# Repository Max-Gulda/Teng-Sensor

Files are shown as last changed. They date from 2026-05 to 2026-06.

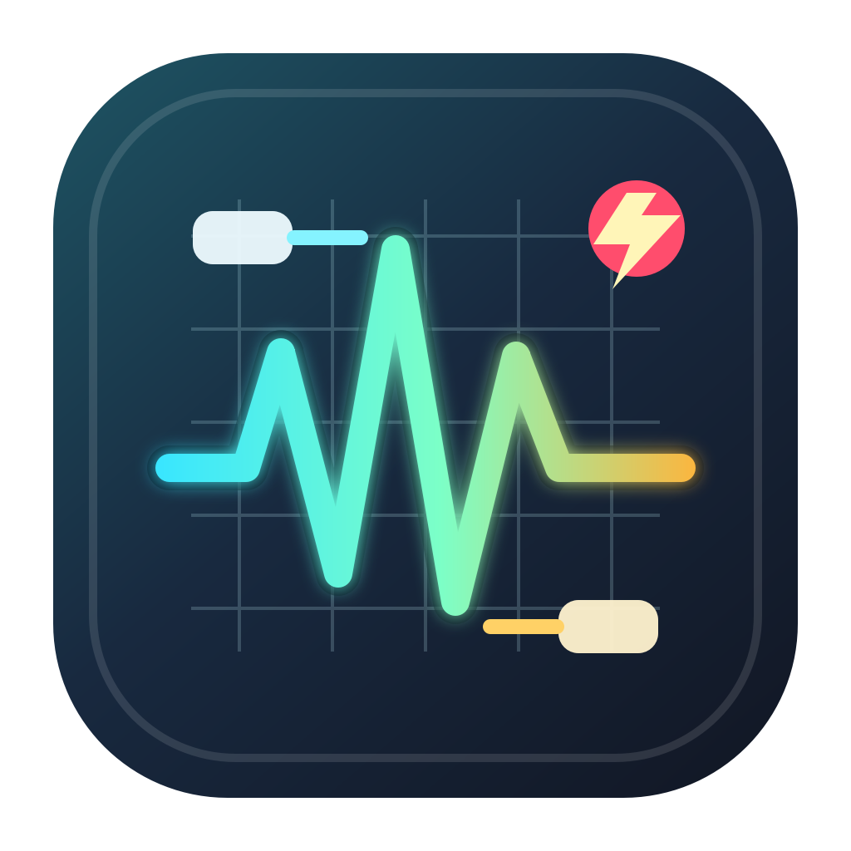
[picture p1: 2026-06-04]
gui/src/ecg_belt_gui/assets/teng-sensor-scope.png

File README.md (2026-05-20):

# TENG Sensor Scope

This repository contains two parts:

- `nrf54/`: Zephyr firmware for the Nordic **nRF54L15 DK target** (`nrf54l15dk/nrf54l15/cpuapp`) used by the course board setup
- `gui/`: a Python BLE scope GUI that displays calibrated ADS131M04 voltage streams

Minimal Zephyr RTOS firmware intended for the course proprietary board setup. The Zephyr build target used for this course setup is:

- `nrf54l15dk/nrf54l15/cpuapp`

The firmware samples **ADS131M04** 24-bit ADC data. All 4 ADC channels are enabled and streamed over BLE as signed raw counts. CH0 and CH1 are intended to be displayed as source voltage through the 100k/15k input dividers; CH2 and CH3 are direct ADC input voltage.

It transmits data over **Bluetooth LE** using custom GATT characteristics plus Nordic UART Service (NUS) for logs and scope commands.

## Attribution

Created by:

- **Jesper Sjöberg** — GitHub: [@repsejs](https://github.com/repsejs) — KTH: **@jessjobe**
- **Max Gulda** — GitHub: [@Max-Gulda](https://github.com/Max-Gulda) — KTH: **@gulda**

## Architecture

### Threads and priorities

| Thread | Priority | What it does | Key code |
|---|---:|---|---|
| Sampling | 5 | Reads ADC on ADS131M04 DRDY falling edges and queues data to BLE | `nrf54/src/sampling/sampling.c` |
| Bluetooth | 7 | Batches and transmits ADC notifications; manages connect/disconnect | `nrf54/src/bluetooth/bluetooth.c`, `nrf54/src/bluetooth/bt_*.c` |
| Main | default | Initialization + periodic CPU load logging | `nrf54/src/main.c` |

### Data flow

```text
ADS131M04 CH0-CH3 ─► sampling_thread ───────────────────────────────────────────────► BLE ADC channel (batched notifications)
LOG_* / printk ─────────────────────────────► NUS (BLE log backend)
```

### Source layout (firmware)

- `nrf54/src/ads131m04_spi/` — ADS131M04 SPI driver + configuration
- `nrf54/src/sampling/` — DRDY-driven sampling thread, queues ADC frames to BLE
- `nrf54/src/bluetooth/` — BLE GATT services, batching, queues, and notifications
- `nrf54/src/ble_log_backend/` — routes Zephyr `LOG_*` output over BLE (NUS)

### ADS131M04 notes

- The old `ads131m02_spi` module was renamed to `ads131m04_spi`.
- The driver parses 4 ADC channels and exposes CH0, CH1, CH2, and CH3 in `ads131m04_data_t`.
- The default setup in `ads131m04_full_setup()` enables all four channels.
- CH0 and CH1 have 100k/15k dividers and are converted to source voltage in the GUI.
- CH2 and CH3 have no divider and are converted to direct ADC input voltage in the GUI.
- The main custom BLE ADC payload carries timestamp + CH0 + CH1 + CH2 + CH3.
- Sampling is driven by the ADS131M04 DRDY pin. The default ADC OSR is 8192 (500 SPS), and the GUI can switch among the standard ADS131M04 output data rates.

## Build and run (VS Code + nRF Connect extension)

### Important (VS Code workspace)

When using the **nRF Connect for VS Code** extension, make sure the **opened workspace folder is `nrf54/`** (not the repo root). Otherwise the extension may not detect the application correctly.

### Prerequisites

- VS Code
- **nRF Connect for VS Code** extension installed (Nordic Semiconductor)
- A working nRF Connect SDK toolchain (the extension can install/manage this)
- The **course proprietary board** connected over USB (uses the nRF54L15 DK target)

### Open the project

1. Open this folder in VS Code.
2. In the nRF Connect sidebar:
   - Select the **application**: `nrf54/`
   - Select the board: `nrf54l15dk/nrf54l15/cpuapp`.

### Build

Use the nRF Connect extension’s **Build** action. This project uses Zephyr sysbuild (MCUboot enabled), matching:

```bash
cd nrf54
west build -b nrf54l15dk/nrf54l15/cpuapp --sysbuild
```

### Flash

Use the nRF Connect extension’s **Flash** action, or from a terminal:

```bash
west flash
```

### View logs / verify it runs

You have two common options:

- **UART/serial logs**: use the extension’s serial monitor, or:

```bash
west espresso
```

- **BLE logs over NUS**: connect with a NUS-capable client and view logs streamed by the BLE log backend (enabled in `nrf54/src/main.c`).

## IntelliSense note (students)

This repo is configured to work with VS Code’s **C/C++ IntelliSense**. For full, correct include paths/macros, build once so Zephyr generates:

- `nrf54/build/compile_commands.json`

After the first build, IntelliSense should work.

## Bluetooth DFU (nRF Device Manager)

After building, the build directory will contain a DFU package:

- `nrf54/build/dfu_application.zip`

To flash **over Bluetooth** using the **nRF Device Manager** mobile app:

1. Flash once over USB initially (so the device has the bootloader + BLE DFU enabled).
2. Power the device and connect to it in **nRF Device Manager**.
3. Choose **DFU / Update firmware** (wording varies by app version).
4. Select `dfu_application.zip` and start the update.
5. Wait for the device to reboot and reconnect.

## GUI (Python)

To run the BLE scope GUI:

```bash
cd gui
uv sync
uv run teng-sensor-scope
```

Use **Settings** in the GUI to choose visible channels and plot window length.

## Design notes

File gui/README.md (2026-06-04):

# TENG Sensor Scope GUI (Python)

Desktop GUI that connects over BLE and displays:

- Calibrated ADS131M04 channel voltages CH0, CH1, CH2, and CH3
- Per-channel visibility, plot window length, and display filter controls
- Dark and light UI themes
- CSV recordings saved under `Recordings/` in the repository root
- Firmware logs over NUS in the launching terminal

## Run (uv)

From the repo root:

```bash
cd gui
uv sync
uv run teng-sensor-scope
```

The old `uv run ecg-belt-gui` command remains as a compatibility alias.

## Voltage Scaling

- The firmware streams raw signed ADS131M04 counts.
- CH0 and CH1 use the 100k/15k voltage dividers and are displayed as source voltage.
- CH2 and CH3 have no divider and are displayed as direct ADC input voltage.
- Per-channel trim constants live in `src/ecg_belt_gui/app.py` as `CHANNEL_TRIM_GAIN` and `CHANNEL_TRIM_OFFSET_V`.

## Scope Settings

Use the **Settings** button to:

- Hide or show individual channels.
- Set the visible plot window in seconds.
- Set the ADS131M04 output data rate from the standard OSR-derived rates.
- Enable and tune the display-only Butterworth low-pass filter cutoff.
- Enable or disable the display-only 50 Hz notch filter.
- Switch between dark and light themes.
- Firmware samples on ADS131M04 DRDY events at the selected output data rate.

## Recording

Use the **Record** button while connected to write incoming ADC samples to CSV. Each recording is saved as `Recordings/teng_recording_YYYYMMDD_HHMMSS.csv` from the repository root and includes sample index plus calibrated CH0-CH3 values in mV.

## Notes

- The firmware device name is expected to be `TENG_Scope`.
- BLE UUIDs are defined in `nrf54/src/bluetooth/bluetooth.c`.
- GUI toolkit: Qt via `PySide6`.

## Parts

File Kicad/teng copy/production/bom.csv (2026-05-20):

Designator | Footprint | Quantity | Value | LCSC Part #
C1, C19, C2, C20 | 0805 | 4 | 10nF
C10, C12, C14 | 0402 | 3 | 1uF
C11 | 0402 | 1 | 220nF
C13 | 0402 | 1 | 22uF
C15, C16, C17, C18, C22, C25, C3, C4, C5, C6 | 0805 | 10 | 100nF
C21 | 0805 | 1 | 33pF
C23 | 0805 | 1 | 15pF
C24 | 0805 | 1 | 4.7uF
C26 | 0805 | 1 | 22uF
C27 | 0805 | 1 | 1uF
C28 | 0805 | 1 | 2.2uF
C7, C9 | 0402 | 2 | 10uF
C8 | 0402 | 1 | 2.2uF
J10, J9 | SolderWire-0.127sqmm_1x01_D0.48mm_OD1mm | 2 | Conn_01x01_Pin
J11, J12 | SolderWirePad_1x01_SMD_1x2mm | 2 | GND
J13 | SolderWirePad_1x01_SMD_1x2mm | 1 | VDD
J14 | SolderWirePad_1x01_SMD_1x2mm | 1 | SWDCLK
J15 | SolderWirePad_1x01_SMD_1x2mm | 1 | SWDIO
J5 | SolderWire-0.15sqmm_1x01_D0.5mm_OD1.5mm | 1 | AIN1N-input
J6, J7, J8 | SolderWire-0.127sqmm_1x01_D0.48mm_OD1mm | 3 | AIN1N-input
L1 | L0603 | 1 | SDFL1608Q2R2KTF | C1033
L2, L3 | IND-SMD_L3.8-W3.8_CDRH3D23NP | 2 | CDRH3D23NP-150MC | C323529
LED1, LED2 | LED0603-RD | 2 | Blue light 0603 | C2288
R1, R16, R7, R9 | 0805 | 4 | 100k
R10, R11 | 0402 | 2 | 5k1
R12 | 0402 | 1 | 1k5
R13 | 0402 | 1 | 10k
R14 | 0402 | 1 | 4k7
R15, R17, R6, R8 | 0805 | 4 | 15k
R18, R19, R2, R20, R21, R3, R4, R5 | 0805 | 8 | 1k
R22 | 0402 | 1 | 1k
R23 | 0805 | 1 | 549k
R24 | 0805 | 1 | 324k
RF1, RF2, RF3, RF5 | BNC-TH_DOSIN-801-0080 | 4 | DOSIN-801-0080 | C521219
SW1 | SW-SMD_XDMK-12C01-25 | 1 | XDMK-12C01-25 | C7498220
U1, U6, U7, U8 | SOIC-8_L5.0-W4.0-P1.27-LS6.0-BL | 4 | ADA4530-1ARZ-R7 | C77380
U10 | IND-SMD_L3.8-W3.8_YPRH3D16 | 1 | CDRH3D16-100 | C9900018502
U3 | holyIOT | 1 | ~
U4 | QFN-24_L4.0-W4.0-P0.50-TL-EP2.7 | 1 | NPM1100-QDAA-R | C5816773
U5 | SOP65P640X120-20N | 1 | ADS131M04IPWR
U9 | DFN-10_L3.0-W3.0-P0.50-BL-EP-3 | 1 | LT3487EDD#PBF | C580078
USBC1 | USB-C_SMD-TYPE-C-31-M-12_1 | 1 | TYPE-C-31-M-12 | C165948

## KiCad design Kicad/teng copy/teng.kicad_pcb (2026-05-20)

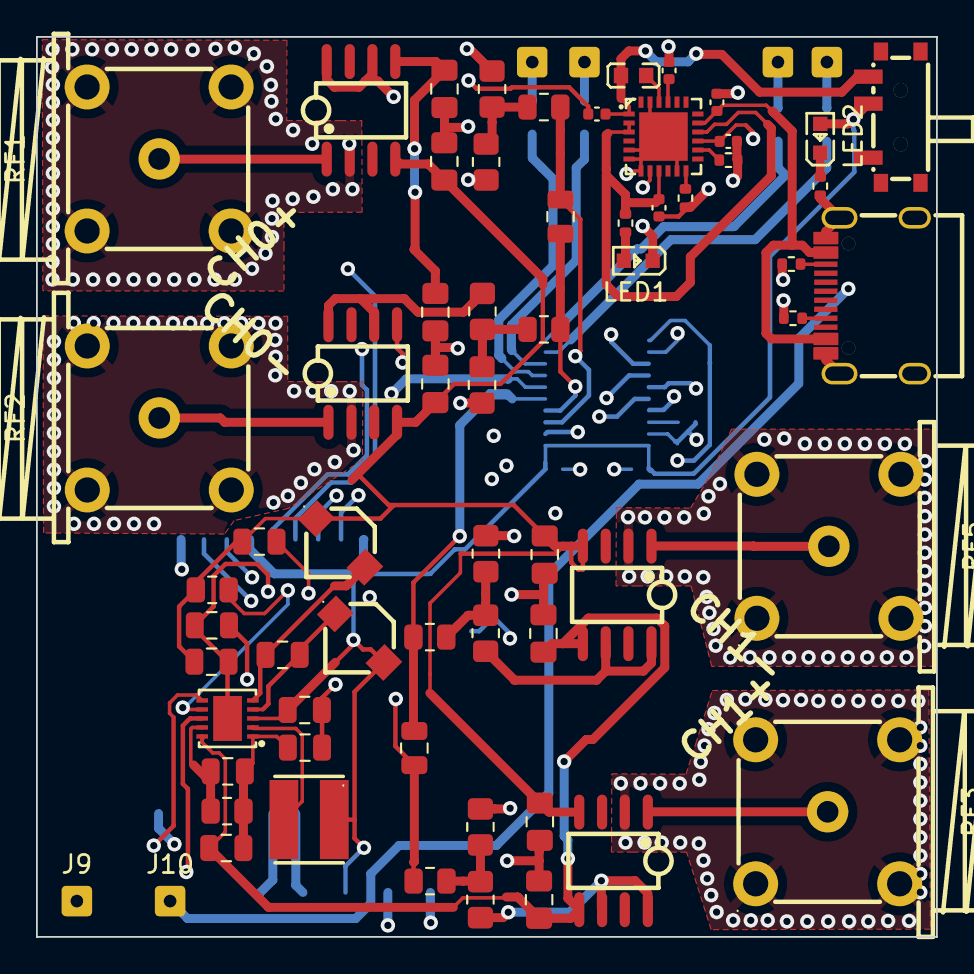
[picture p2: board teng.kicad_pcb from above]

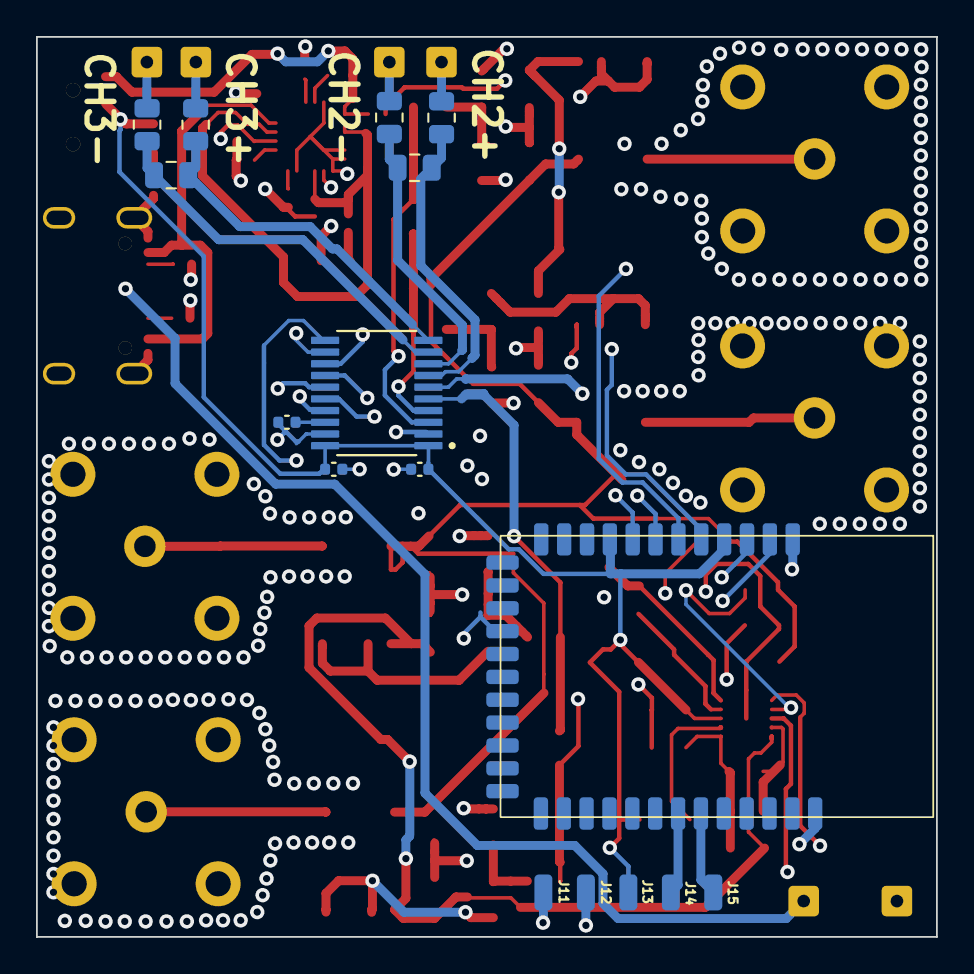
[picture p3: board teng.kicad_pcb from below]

Board: 4 copper layers, 50.0 x 50.0 mm, 83 parts (20 on the bottom side), 62 nets.

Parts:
C1, C2, C19, C20: 10nF; C_0805_2012Metric
C3, C4, C5, C6, C15, C16, C17, C18: 100nF; C_0805_2012Metric_Pad1.18x1.45mm_HandSolder
C7, C9: 10uF; C_0402_1005Metric
C8: 2.2uF; C_0402_1005Metric
C10, C12, C14: 1uF; C_0402_1005Metric
C11: 220nF; C_0402_1005Metric
C13: 22uF; C_0402_1005Metric
C21: 33pF; C_0805_2012Metric
C22, C25: 100nF; C_0805_2012Metric
C23: 15pF; C_0805_2012Metric
C24: 4.7uF; C_0805_2012Metric
C26: 22uF; C_0805_2012Metric
C27: 1uF; C_0805_2012Metric
C28: 2.2uF; C_0805_2012Metric
J5: AIN1N-input; SolderWire-0.15sqmm_1x01_D0.5mm_OD1.5mm
J6, J7, J8: AIN1N-input; SolderWire-0.127sqmm_1x01_D0.48mm_OD1mm
J9, J10: Conn_01x01_Pin; SolderWire-0.127sqmm_1x01_D0.48mm_OD1mm
J11, J12: GND; SolderWirePad_1x01_SMD_1x2mm
J13: VDD; SolderWirePad_1x01_SMD_1x2mm
J14: SWDCLK; SolderWirePad_1x01_SMD_1x2mm
J15: SWDIO; SolderWirePad_1x01_SMD_1x2mm
L1: SDFL1608Q2R2KTF; L0603
L2, L3: CDRH3D23NP-150MC; IND-SMD_L3.8-W3.8_CDRH3D23NP
LED1, LED2: Blue light 0603; LED0603-RD
R1, R7, R9, R16: 100k; R_0805_2012Metric_Pad1.20x1.40mm_HandSolder
R2, R3, R4, R5, R18, R19, R20, R21: 1k; R_0805_2012Metric
R6, R8, R15, R17: 15k; R_0805_2012Metric_Pad1.20x1.40mm_HandSolder
R10, R11: 5k1; R_0402_1005Metric
R12: 1k5; R_0402_1005Metric
R13: 10k; R_0402_1005Metric
R14: 4k7; R_0402_1005Metric
R22: 1k; R_0402_1005Metric
R23: 549k; R_0805_2012Metric
R24: 324k; R_0805_2012Metric
RF1, RF2, RF3, RF5: DOSIN-801-0080; BNC-TH_DOSIN-801-0080
SW1: XDMK-12C01-25; SW-SMD_XDMK-12C01-25
U1, U6, U7, U8: ADA4530-1ARZ-R7; SOIC-8_L5.0-W4.0-P1.27-LS6.0-BL
U3: holyIOT
U4: NPM1100-QDAA-R; QFN-24_L4.0-W4.0-P0.50-TL-EP2.7
U5: ADS131M04IPWR; SOP65P640X120-20N
U9: LT3487EDD#PBF; DFN-10_L3.0-W3.0-P0.50-BL-EP-3
U10: CDRH3D16-100; IND-SMD_L3.8-W3.8_YPRH3D16
USBC1: TYPE-C-31-M-12; USB-C_SMD-TYPE-C-31-M-12_1

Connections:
AIN0N: C2.2, R5.2, U5.4 (AIN0N)
AIN0P: C2.1, R4.2, U5.3 (AIN0P)
AIN1N: C1.2, R3.2, U5.5 (AIN1N)
AIN1P: C1.1, R2.2, U5.6 (AIN1P)
AIN2N: C19.2, R19.2, U5.8 (AIN2N)
AIN2P: C19.1, R18.2, U5.7 (AIN2P)
AIN3N: C20.2, R21.2, U5.9 (AIN3N)
AIN3P: C20.1, R20.2, U5.10 (AIN3P)
CHG: LED1.1 (K), U4.8 (CHG)
CLKIN: U3.16 (P1.08), U5.17 (CLKIN)
CS: U3.6 (P1.12), U5.12 (~CS)
DIN: U3.7 (P1.13), U5.16 (DIN)
DOUT: U3.8 (P1.14), U5.15 (DOUT)
DRDY: U3.2 (P1.09), U5.13 (~DRDY)
GRD0N: RF2.1, RF2.2, RF2.3, RF2.4, U7.2 (GRD)
GRD0P: RF1.1, RF1.2, RF1.3, RF1.4, U6.2 (GRD)
GRD1N: RF5.1, RF5.2, RF5.3, RF5.4, U1.2 (GRD)
GRD1P: RF3.1, RF3.2, RF3.3, RF3.4, U8.2 (GRD)
unnamed: J5.1, R18.1
unnamed: J6.1, R19.1
unnamed: J7.1, R20.1
unnamed: J8.1, R21.1
unnamed: LED1.2 (A), R22.1
unnamed: LED2.1 (K), R14.1
unnamed: R1.2, R5.1, R6.1
unnamed: R4.1, R7.2, R8.1
unnamed: R3.1, R9.2, R15.1
unnamed: R2.1, R16.2, R17.1
unnamed: RF5.5, U1.1 (+IN)
unnamed: R9.1, U1.6 (OUT), U1.8 (–IN)
unnamed: C9.1, U4.21 (DEC)
unnamed: R12.2, U4.12 (ICHG)
unnamed: R13.2, U4.14 (NTC)
unnamed: L1.2, U4.22 (SW)
unnamed: C11.1, U5.18 (CAP)
unnamed: RF1.5, U6.1 (+IN)
unnamed: R7.1, U6.6 (OUT), U6.8 (–IN)
unnamed: RF2.5, U7.1 (+IN)
unnamed: R1.1, U7.6 (OUT), U7.8 (–IN)
unnamed: RF3.5, U8.1 (+IN)
unnamed: R16.1, U8.6 (OUT), U8.8 (–IN)
unnamed: C23.1, C24.1, C25.1, R23.1, U9.1 (CAP)
unnamed: C28.2, L3.2, U9.5 (DN)
unnamed: C21.2, R24.2, U9.7 (FBN)
unnamed: C23.2, R23.2, U9.9 (FBP)
unnamed: C22.1, U9.8 (RUN/SS)
unnamed: C28.1, L2.1, U9.4 (SWN)
unnamed: U9.2 (SWP), U10.2
unnamed: R11.1, USBC1.A5 (CC1)
unnamed: R10.1, USBC1.B5 (CC2)
SCLK: U3.5 (P1.11), U5.14 (SCLK)
SWDCLK: J14.1, U3.30 (SWDCLK)
SWDIO: J15.1, U3.31 (SWDIO)
SYNC/RESET: U3.3 (P1.10), U5.11 (~SYNC/~RESET)
VBUS: C8.2, U4.17 (VBUS), USBC1.A4B9 (VBUS), USBC1.B4A9 (VBUS)
VDD: C12.1, C14.1, C27.1, J13.1, L2.2, LED2.2 (A), SW1.2, U3.4 (VDD), U3.9 (VDDM), U5.1 (AVDD), U5.20 (DVDD), U9.3 (VBAT), U9.6 (VIN), U10.1
VNEG: C3.1, C5.1, C6.1, C16.1, C21.1, C26.1, L3.1, R24.1, U1.4 (V–), U6.4 (V–), U7.4 (V–), U8.4 (V–)
VOUT: C7.1, L1.1, SW1.1, U4.1 (VOUTB)
VPOS: C4.1, C15.1, C17.1, C18.1, C25.2, U1.5 (V+), U6.5 (V+), U7.5 (V+), U8.5 (V+), U9.10 (VPOS)
VSYS: C13.1, R22.2, U4.2 (VOUTBSET1), U4.3 (VOUTBSET2), U4.9 (VTERMSET), U4.16 (VSYS)
bat+: C10.1, J10.1, U4.15 (VBAT)
bat-: C3.2, C4.2, C5.2, C6.2, C7.2, C8.1, C9.2, C10.2, C11.2, C12.2, C13.2, C14.2, C15.2, C16.2, C17.2, C18.2, C22.2, C24.2, C26.2, C27.2, J9.1, J11.1, J12.1, R6.2, R8.2, R10.2, R11.2, R12.1, R13.1, R14.2, R15.2, R17.2, U3.1 (GND), U3.36 (GND), U4.5 (ISET), U4.6 (SHPACT), U4.7 (MODE), U4.11 (SHPHLD), U4.23 (PVSS), U4.25 (EP), U5.2 (AGND), U5.19 (DGND), U9.11 (GND), USBC1.1 (EH), USBC1.2 (EH), USBC1.3 (EH), USBC1.4 (EH), USBC1.A1B12 (GND), USBC1.B1A12 (GND)

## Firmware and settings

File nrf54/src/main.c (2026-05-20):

/*
 * SPDX-License-Identifier: MIT
 * Copyright (c) 2026 Jesper Sjöberg (@repsejs, KTH: @jessjobe)
 * Copyright (c) 2026 Max Gulda (@Max-Gulda, KTH: @gulda)
 */

#include <zephyr/kernel.h>
#include "ads131m04_spi.h"
#include "sampling.h"
#include "bluetooth.h"
#include "ble_log_backend.h"
#include <zephyr/logging/log.h>
#include <zephyr/debug/cpu_load.h>

LOG_MODULE_REGISTER(main, LOG_LEVEL_INF);

int main(void) {
    int err;
    ads131m04_config_t *adc_config;

    LOG_INF("=== ADS131M04 oscilloscope sampling (DRDY-driven) ===");
    
    /* ------------ INIT BLUETOOTH START ------------*/

    /* Initialize Bluetooth */
    err = bluetooth_init();
    if (err < 0) {
        LOG_ERR("Failed to initialize Bluetooth (%d)", err);
        return 0;
    }

    /* Start Bluetooth advertising */
    err = bluetooth_start();
    if (err < 0) {
        LOG_ERR("Failed to start Bluetooth (%d)", err);
        return 0;
    }

    /* Enable BLE log backend — messages stream to any NUS-connected terminal */
    ble_log_backend_enable();

    //k_msleep(20000);
    /* ------------ INIT BLUETOOTH END ------------*/

    /* ------------ INIT ADS131M04 START -------------*/
    /* Get ADC configuration */
    adc_config = ads131m04_get_config();

    /* Perform full ADC setup */
    err = ads131m04_full_setup(adc_config);
    if (err < 0) {
        LOG_ERR("Failed to setup ADC");
        return 0;
    }

    /* ------------ INIT ADS131M04 END --------------*/

    /* ------------ INIT SAMPLING START ------------*/

    /* Initialize sampling system */
    err = sampling_init(adc_config);
    if (err < 0) {
        LOG_ERR("Failed to initialize sampling system");
        return 0;
    }

    /* Start sampling */
    err = sampling_start();
    if (err < 0) {
        LOG_ERR("Failed to start sampling");
        return 0;
    }

    /* ------------ INIT BLUETOOTH END ------------*/
    int cpu_load = 0;

    /* Main thread monitors CPU load */
    while (1) {
        k_msleep(10000);
        cpu_load = cpu_load_get(false);
        if (cpu_load >= 0) {
            LOG_INF("CPU Usage: %d.%d%%", cpu_load / 10, cpu_load % 10);
        } else {
            LOG_ERR("CPU Usage: Error %d", cpu_load);
        }
    }

    return 0;
}

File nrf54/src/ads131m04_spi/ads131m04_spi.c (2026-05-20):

/*
 * SPDX-License-Identifier: MIT
 * Copyright (c) 2026 Jesper Sjöberg (@repsejs, KTH: @jessjobe)
 * Copyright (c) 2026 Max Gulda (@Max-Gulda, KTH: @gulda)
 */

/**
 * @file ads131m04_spi.c
 * @brief ADS131M04 24-bit ADC SPI driver implementation for Zephyr RTOS
 */

#include "ads131m04_spi.h"
#include "../helper/spi_helper.h"
#include <zephyr/logging/log.h>

LOG_MODULE_REGISTER(ads131m04_spi, LOG_LEVEL_NONE);

/* Timing delays (in microseconds) */
#define ADS131M04_RESET_DELAY_US 1

static const uint16_t gain_masks[ADS131M04_NUM_CHANNELS] = {
    ADS131M04_REGMASK_GAIN_PGAGAIN0,
    ADS131M04_REGMASK_GAIN_PGAGAIN1,
    ADS131M04_REGMASK_GAIN_PGAGAIN2,
    ADS131M04_REGMASK_GAIN_PGAGAIN3,
};

static const uint8_t cfg_registers[ADS131M04_NUM_CHANNELS] = {
    ADS131M04_REG_CH0_CFG,
    ADS131M04_REG_CH1_CFG,
    ADS131M04_REG_CH2_CFG,
    ADS131M04_REG_CH3_CFG,
};

static const uint8_t ocal_msb_registers[ADS131M04_NUM_CHANNELS] = {
    ADS131M04_REG_CH0_OCAL_MSB,
    ADS131M04_REG_CH1_OCAL_MSB,
    ADS131M04_REG_CH2_OCAL_MSB,
    ADS131M04_REG_CH3_OCAL_MSB,
};

static const uint8_t ocal_lsb_registers[ADS131M04_NUM_CHANNELS] = {
    ADS131M04_REG_CH0_OCAL_LSB,
    ADS131M04_REG_CH1_OCAL_LSB,
    ADS131M04_REG_CH2_OCAL_LSB,
    ADS131M04_REG_CH3_OCAL_LSB,
};

static const uint16_t channel_enable_masks[ADS131M04_NUM_CHANNELS] = {
    ADS131M04_REGMASK_CLOCK_CH0_EN,
    ADS131M04_REGMASK_CLOCK_CH1_EN,
    ADS131M04_REGMASK_CLOCK_CH2_EN,
    ADS131M04_REGMASK_CLOCK_CH3_EN,
};

/**
 * @brief Convert 24-bit two's complement to signed 32-bit integer
 */
static inline int32_t twos_complement_24bit(int32_t val) {
    if ((val >> 23) & 0x01) {
        return val - (1 << 24);
    }
    return val;
}

static int32_t parse_adc_word(const uint8_t *rx_buf, size_t word_index) {
    size_t offset = word_index * ADS131M04_WORD_LEN_BYTES;
    int32_t raw = ((int32_t)rx_buf[offset] << 16) |
                  ((int32_t)rx_buf[offset + 1] << 8) |
                  rx_buf[offset + 2];

    return twos_complement_24bit(raw & 0x00FFFFFF);
}

/**
 * @brief Parse channel data from a raw ADC SPI response buffer
 */
static void parse_adc_data(const uint8_t *rx_buf, ads131m04_data_t *data) {
    data->ch0 = parse_adc_word(rx_buf, 1);
    data->ch1 = parse_adc_word(rx_buf, 2);
    data->ch2 = parse_adc_word(rx_buf, 3);
    data->ch3 = parse_adc_word(rx_buf, 4);
}

static int32_t get_channel_sample(const ads131m04_data_t *data, uint8_t channel) {
    switch (channel) {
        case 0:
            return data->ch0;
        case 1:
            return data->ch1;
        case 2:
            return data->ch2;
        case 3:
            return data->ch3;
        default:
            return 0;
    }
}

static int ads131m04_gain_to_reg_value(uint8_t gain_x, uint8_t *reg_value) {
    if (reg_value == NULL) {
        return -EINVAL;
    }

    switch (gain_x) {
        case ADS131M04_GAIN_1:
            *reg_value = 0b000;
            return 0;
        case ADS131M04_GAIN_2:
            *reg_value = 0b001;
            return 0;
        case ADS131M04_GAIN_4:
            *reg_value = 0b010;
            return 0;
        case ADS131M04_GAIN_8:
            *reg_value = 0b011;
            return 0;
        case ADS131M04_GAIN_16:
            *reg_value = 0b100;
            return 0;
        case ADS131M04_GAIN_32:
            *reg_value = 0b101;
            return 0;
        case ADS131M04_GAIN_64:
            *reg_value = 0b110;
            return 0;
        case ADS131M04_GAIN_128:
            *reg_value = 0b111;
            return 0;
        default:
            return -EINVAL;
    }
}

static int ads131m04_set_channel_offset_calibration(ads131m04_config_t *config, uint8_t channel,
    int32_t offset) {
    uint32_t raw_offset = (uint32_t)offset & 0x00FFFFFF;
    uint16_t msb = (raw_offset >> 8) & 0xFFFF;
    uint8_t lsb = raw_offset & 0xFF;

    if (channel >= ADS131M04_NUM_CHANNELS) {
        LOG_ERR("Invalid channel: %d", channel);
        return -EINVAL;
    }

    int ret = ads131m04_write_register_masked(config, ocal_msb_registers[channel], msb, 0xFFFF);
    if (ret < 0) {
        return ret;
    }

    return ads131m04_write_register_masked(config, ocal_lsb_registers[channel], lsb,
        ADS131M04_REGMASK_CHX_OCAL0_LSB);
}

int ads131m04_init(ads131m04_config_t *config) {
    int ret;

    if (!device_is_ready(config->spi_dev)) {
        LOG_ERR("SPI device not ready");
        return -ENODEV;
    }

    if (config->drdy_gpio.port != NULL) {
        if (!gpio_is_ready_dt(&config->drdy_gpio)) {
            LOG_ERR("DRDY GPIO not ready");
            return -ENODEV;
        }

        ret = gpio_pin_configure_dt(&config->drdy_gpio, GPIO_INPUT);
        if (ret < 0) {
            LOG_ERR("Failed to configure DRDY GPIO: %d", ret);
            return ret;
        }
    }

    if (config->reset_gpio.port != NULL) {
        if (!gpio_is_ready_dt(&config->reset_gpio)) {
            LOG_ERR("RESET GPIO not ready");
            return -ENODEV;
        }

        ret = gpio_pin_configure_dt(&config->reset_gpio, GPIO_OUTPUT_INACTIVE);
        if (ret < 0) {
            LOG_ERR("Failed to configure RESET GPIO: %d", ret);
            return ret;
        }

        LOG_DBG("RESET GPIO configured as output inactive (not in reset)");
    }

    LOG_INF("ADS131M04 initialized");
    return 0;
}

int ads131m04_reset(ads131m04_config_t *config) {
    int ret;
    uint16_t response;

    ret = ads131m04_send_command(config, ADS131M04_CMD_RESET, &response);
    if (ret < 0) {
        LOG_ERR("Reset command failed: %d", ret);
        return ret;
    }

    k_busy_wait(ADS131M04_RESET_DELAY_US);

    LOG_INF("ADS131M04 reset complete");
    return 0;
}
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

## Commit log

2026-03-27 gui: implement BLE streaming Qt app
    Use PySide6 + pyqtgraph with threaded BLE scan/streaming, device dropdown selection, stacked plots, NUS log forwarding to terminal, and basic ECG conditioning toggles.
2026-03-27 gui: remove unused log panel
    Logs are printed to stdout, so drop the in-window log label and text box.
2026-04-08 firmware: migrate ADC path to ADS131M04
2026-04-08 firmware: update gain settings to use user-facing multipliers and add gain conversion function, fixed read_register bug
    [ads131m04_spi.c, ads131m04_spi.h]
2026-04-08 refactor: clean up code formatting and improve error logging for ADC and IMU reads
    [sampling.c]
2026-05-20 Update TENG sensor firmware and data collector
    [bom.csv, designators.csv, positions.csv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]
2026-06-04 changed to interrupt driven
2026-06-04 Add SVG asset for Teng Sensor Scope visualization
